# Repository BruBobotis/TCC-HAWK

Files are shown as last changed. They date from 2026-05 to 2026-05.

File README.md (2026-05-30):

<div align="center">

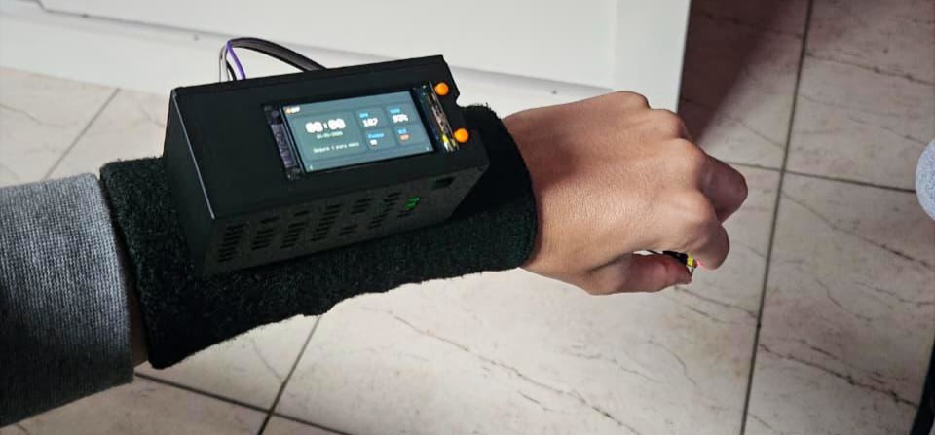
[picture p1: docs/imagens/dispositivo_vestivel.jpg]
Logo HAWK


# TCC-HAWK  
### Health Assistant Watch Kare

Sistema vestível para cuidado geriátrico com monitoramento de sinais vitais, detecção de quedas, comunicação BLE e aplicativo Android nativo.

</div>

<p align="center">
  
  
  
  
  
  
</p>

<p align="center">
  <a href="#visão-geral">Visão Geral</a> •
  <a href="#principais-funcionalidades">Funcionalidades</a> •
  <a href="#arquitetura-geral-do-sistema">Arquitetura</a> •
  <a href="#aplicativo-android">Aplicativo</a> •
  <a href="#como-executar-o-projeto">Como Executar</a>
</p>

## Visão Geral

O HAWK é um sistema de monitoramento geriátrico desenvolvido como Trabalho de Conclusão de Curso em Engenharia de Controle e Automação para Faculdade Engenheiro Salvador Arena. O projeto consiste em um dispositivo vestível, no formato de relógio inteligente, integrado a um aplicativo Android nativo. A solução foi criada com o objetivo de auxiliar no acompanhamento de idosos, permitindo a visualização de dados fisiológicos, monitoramento de movimento, detecção de quedas, emissão de alertas e futura integração com armazenamento em nuvem.

O sistema foi desenvolvido ao longo de aproximadamente um ano, passando por etapas de prototipagem eletrônica, programação embarcada, desenvolvimento mobile, comunicação Bluetooth Low Energy, testes funcionais, documentação técnica e refinamento da interface.

O nome HAWK foi escolhido em referência ao falcão, símbolo de vigilância, atenção e resposta rápida. Essa ideia representa a proposta do sistema: acompanhar continuamente o usuário e gerar alertas em situações críticas.
<p align="center">
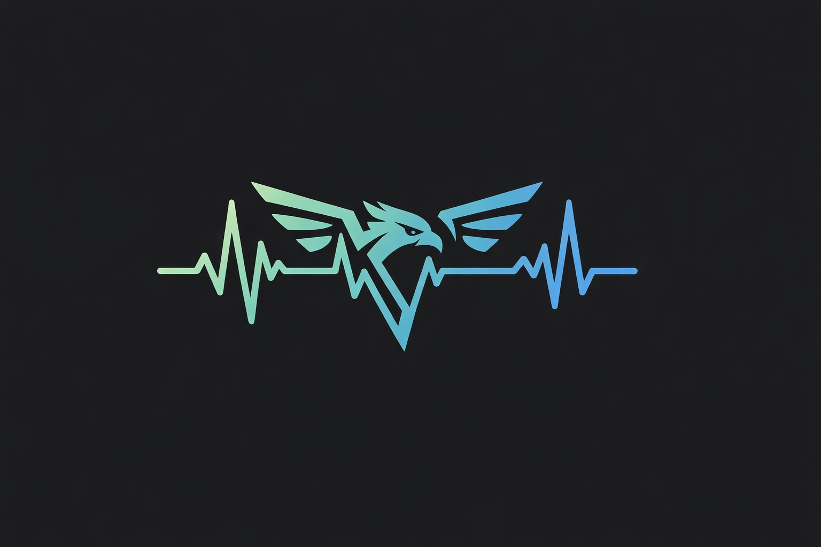
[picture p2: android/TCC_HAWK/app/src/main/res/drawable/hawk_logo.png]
Logo do Projeto HAWK
  
</p>

---

## Equipe de Desenvolvimento

Projeto desenvolvido como Projeto Final de Curso em Engenharia de Controle e Automação pela Faculdade Engenheiro Salvador Arena.

| Integrante | RA |
|---|---|
| Bruno Alves Guirado | 062210033 |
| Guilherme Fernando de Oliveira Bezerra | 062210038 |
| Guilherme do Nascimento de Souza | 062210016 |
| Lucas Guedes Pereira | 062210002 |
| Pedro Henrique Mateus Ribeiro | 062220039 |

<!--<p align="center">
  <img src="docs/imagens/theMans.jpeg" width="500" alt="Os vagabundos que um dia houveram sonhar"/>
</p>

* Com aparição do nosso companheiro Vinicius Koiti, que felizmente não estava em nosso grupo.
-->
---

## Objetivo do Projeto

O objetivo principal do projeto é desenvolver um dispositivo vestível capaz de monitorar parâmetros básicos de saúde e movimento de um usuário idoso, transmitindo essas informações para um aplicativo móvel Android. O sistema busca oferecer uma interface simples, intuitiva e acessível, permitindo que o usuário ou cuidador acompanhe dados como frequência cardíaca, saturação de oxigênio, passos, movimento, repouso e eventos de queda.

Além disso, o projeto foi estruturado para permitir futuras expansões, como armazenamento em nuvem, geração automática de relatórios, acesso por cuidadores e integração com banco de dados remoto.

---

## Principais Funcionalidades

O sistema implementa as seguintes funcionalidades:

| Categoria | Funcionalidades |
|---|---|
| Monitoramento | Frequência cardíaca, SpO₂, passos, movimento e repouso |
| Segurança | Detecção de queda, alerta sonoro, vibração e tela cheia |
| Comunicação | Bluetooth Low Energy entre relógio e aplicativo |
| Aplicativo | Dashboard, alertas, relatórios, cuidadores e configurações |
| Personalização | Cadastro do usuário, limites de BPM e SpO₂, lembretes de água, remédio e sono |
| Expansão | Estrutura preparada para integração com banco de dados em nuvem |

---

## Arquitetura Geral do Sistema

A arquitetura do HAWK é composta por duas camadas principais: o sistema embarcado e a aplicação móvel Android.

O sistema embarcado é responsável pela aquisição dos dados dos sensores, processamento local das informações, exibição no display do relógio, controle por botões físicos e comunicação BLE. Já o aplicativo Android atua como interface principal de visualização e controle, recebendo os dados do relógio, exibindo informações ao usuário, gerando alertas e preparando os dados para integração futura com a nuvem.

Fluxo geral:

```text
Sensores → ESP32-S3 → BLE → Aplicativo Android → Alertas / Relatórios / Nuvem
```

<p align="center">
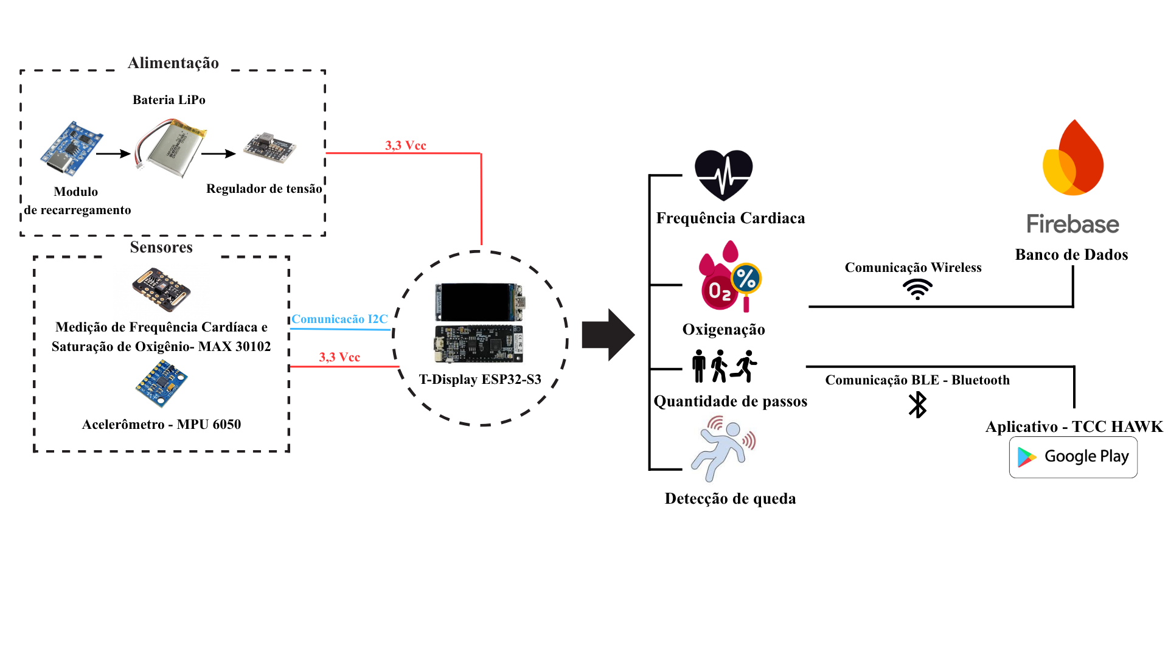
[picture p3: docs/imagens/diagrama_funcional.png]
diagrama funcional
  
</p>

---

## Hardware Utilizado

O protótipo foi desenvolvido utilizando os seguintes componentes principais:

* LilyGo T-Display ESP32-S3;
* Sensor MPU6050;
* Sensor MAX30102;
* Botões físicos para navegação;
* Conexão USB-C para alimentação e programação;
* Jumpers, soldagem e estrutura de montagem;
* Case/protótipo físico para acomodação dos componentes.
<p align="center">
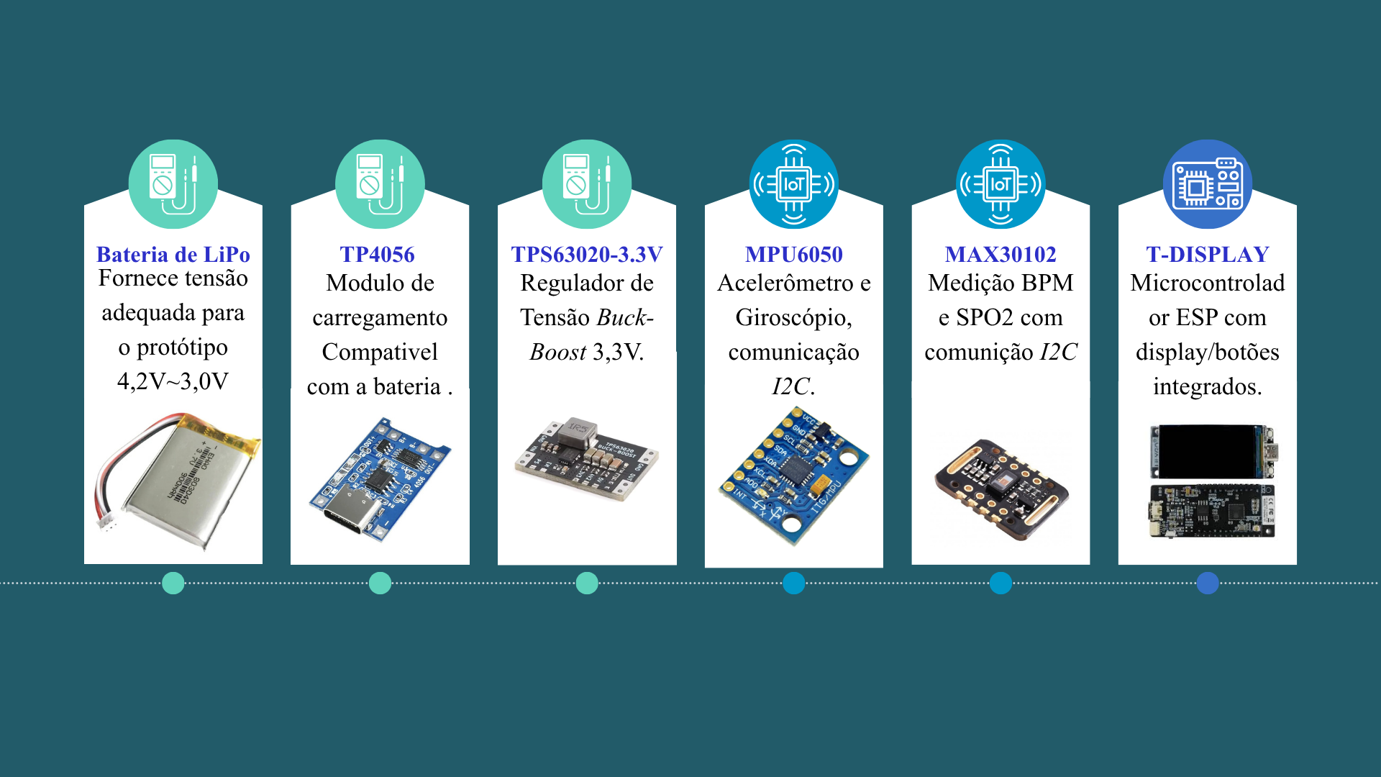
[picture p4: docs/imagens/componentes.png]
componentes
  
</p>

---

## Firmware Embarcado

O firmware foi desenvolvido em C++ utilizando a Arduino IDE. A programação embarcada foi responsável por controlar os sensores, display, botões, lógica de telas, alertas locais e comunicação BLE.

O código embarcado foi estruturado com uma lógica modular, separando as principais responsabilidades do sistema. Entre as funções implementadas estão:

* Inicialização dos periféricos;
* Configuração da comunicação I2C;
* Leitura do MPU6050;
* Leitura do MAX30102;
* Cálculo de passos;
* Análise de movimento;
* Identificação de possível queda;
* Controle das telas do relógio;
* Controle de brilho;
* Recebimento de comandos BLE;
* Envio periódico de dados para o aplicativo.

A interface do relógio foi organizada por uma máquina de estados, permitindo alternância entre telas de horário, dados de saúde, passos, alertas e configurações. Essa abordagem facilitou a navegação por botões físicos e organizou melhor a atualização das informações no display.

---

## Sensores

### MPU6050

O MPU6050 foi utilizado para leitura de aceleração nos três eixos. A partir desses dados, o sistema realiza a análise de movimento, contagem de passos e identificação de possível queda.

A detecção de queda foi baseada na análise da variação de aceleração nos eixos X, Y e Z, identificando movimentos bruscos compatíveis com impacto. Quando o relógio identifica uma possível queda, envia ao aplicativo um sinal específico indicando o evento.

### MAX30102

O MAX30102 foi utilizado para estimativa de frequência cardíaca e saturação de oxigênio. As leituras dependem do contato adequado do sensor com a pele, sendo utilizadas no protótipo como valores indicativos. O módulo não possui validação clínica, sendo empregado com finalidade experimental e demonstrativa no contexto do projeto.

---

## Comunicação BLE

A comunicação entre o relógio e o aplicativo Android ocorre por Bluetooth Low Energy. O relógio atua como dispositivo periférico BLE, enquanto o celular atua como dispositivo central.

O fluxo implementado envolve:

1. Inicialização do relógio;
2. Abertura do aplicativo Android;
3. Busca pelo dispositivo BLE;
4. Conexão entre celular e relógio;
5. Descoberta dos serviços e características;
6. Habilitação de notificações;
7. Sincronização de data e hora;
8. Envio periódico dos dados do relógio para o aplicativo;
9. Envio de comandos do aplicativo para o relógio.

O payload enviado pelo relógio inclui informações como:

```text
BPM
SpO2
Passos
Queda
Aceleração X
Aceleração Y
Aceleração Z
Status do MPU
Status do sensor de dedo
```

O aplicativo interpreta esses dados e atualiza a interface em tempo real.

---

## Aplicativo Android

O aplicativo móvel foi desenvolvido em Kotlin utilizando Android Studio e Jetpack Compose. Ele foi projetado para ser a principal interface de interação do sistema, exibindo os dados recebidos do relógio e permitindo o gerenciamento de alertas, relatórios e configurações.

A arquitetura do aplicativo foi organizada em camadas:

* Interface gráfica em Jetpack Compose;
* ViewModels para controle de estado;
* Repositório para comunicação BLE;
* Modelos de dados;
* Sistema de alertas;
* Estrutura inicial para comunicação com nuvem.

---

## Telas do Aplicativo

O aplicativo possui as seguintes telas principais:

### Dashboard

A tela principal apresenta os principais dados monitorados pelo relógio:

* Frequência cardíaca;
* Saturação de oxigênio;
* Passos;
* Tempo em movimento;
* Tempo em repouso;
* Dados do acelerômetro;
* Status de queda;
* Status de conexão com o relógio;
* Relatório diário de saúde.

Os cards foram refinados para uma interface mais limpa, moderna e premium, com cores suaves, ícones, organização visual e atualização dinâmica dos dados.

### Alertas

A tela de alertas registra eventos importantes, como:

* Queda detectada;
* Batimento alto;
* Batimento baixo;
* Oxigenação baixa;
* Lembretes de hidratação;
* Lembretes de remédio;
* Lembretes de sono;
* Alertas gerais.

Os alertas críticos são exibidos em tela cheia, com som, vibração e notificação visual.

<p align="center">
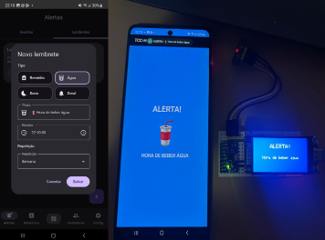
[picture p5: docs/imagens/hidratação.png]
alerta_agua
  
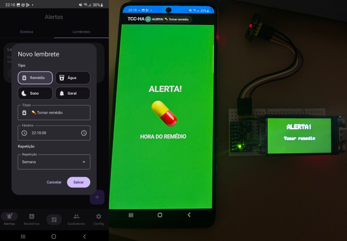
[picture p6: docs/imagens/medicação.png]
alertas_remedio
  
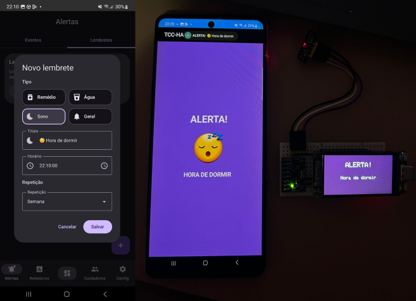
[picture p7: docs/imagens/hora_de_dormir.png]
alertas_dormir
  
</p>

### Relatórios

A tela de relatórios foi planejada para apresentar dados consolidados do usuário, como histórico de batimentos, SpO₂, passos, quedas e eventos críticos. A proposta é permitir acompanhamento diário, semanal e mensal.

### Cuidadores

A tela de cuidadores foi planejada para cadastrar responsáveis pelo usuário monitorado. A ideia é permitir o registro de nome, telefone, e-mail, relação com o paciente e prioridade de contato.

### Configurações

A tela de configurações reúne ajustes gerais do aplicativo e do relógio, como conexão BLE, sincronização de horário, testes de alerta, preferências do sistema e futuras opções de integração com nuvem.

### Cadastro do Usuário

O cadastro inicial coleta informações importantes do paciente, como:

* Nome;
* Data de nascimento;
* Peso;
* Altura;
* Sexo;
* Horários de sono;
* Mobilidade;
* Histórico de quedas;
* Hipertensão;
* Diabetes;
* Problemas cardíacos;
* Problemas respiratórios;
* Uso de medicação contínua;
* Limites personalizados de taquicardia e bradicardia;
* Limites de SpO₂;
* Contato de emergência;
* Observações médicas.

Essas informações permitem personalizar os alertas e melhorar o contexto do monitoramento.

---

## Alerta de Queda

O alerta de queda é uma das principais funcionalidades do projeto. Quando o relógio detecta uma possível queda, envia o status ao aplicativo por BLE. O aplicativo, ao identificar esse evento, executa as seguintes ações:

* Atualiza o card de acelerômetro/queda;
* Registra o evento na tela de alertas;
* Exibe uma tela cheia de alerta crítico;
* Emite som de alarme;
* Ativa vibração;
* Exibe notificação de alta prioridade.

Esse comportamento busca chamar a atenção do usuário ou cuidador em situações de risco.
<p align="center">
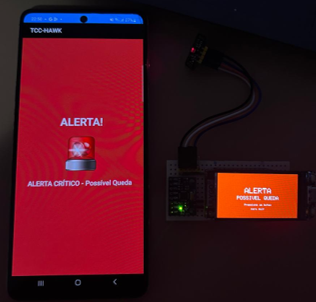
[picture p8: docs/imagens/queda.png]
queda
  
</p>

---

## Integração com Nuvem

Durante o desenvolvimento, foi estudada a integração com banco de dados em nuvem para armazenamento histórico dos dados. Foram avaliadas arquiteturas baseadas em MQTT, InfluxDB e Firebase.

A proposta final considerada para expansão do sistema foi utilizar o aplicativo Android como gateway entre o relógio e a nuvem. Nesse modelo, o relógio envia os dados por BLE ao celular, e o aplicativo organiza essas informações e as envia para uma plataforma em nuvem do Firebase.

Fluxo proposto:

```text
Relógio ESP32 → BLE → Aplicativo Android → Nuvem → Histórico / Relatórios / Cuidadores
```

Para telemetria IoT, o uso de MQTT com banco de séries temporais é uma possibilidade futura. Para integração mais rápida com autenticação, múltiplos dispositivos e sincronização de dados, o Firebase foi considerado uma alternativa adequada.

---

## Testes Realizados

Durante o desenvolvimento foram realizados testes funcionais envolvendo:

* Comunicação BLE entre relógio e celular;
* Sincronização de data e hora;
* Envio de dados do relógio para o aplicativo;
* Atualização dos cards no dashboard;
* Leitura do acelerômetro;
* Detecção de movimento;
* Testes de queda;
* Alertas em tela cheia;
* Vibração e som em eventos críticos;
* Alertas de BPM e SpO₂;
* Funcionamento dos lembretes;
* Testes de interface;
* Validação do payload BLE com nRF Connect.

O nRF Connect foi utilizado como ferramenta auxiliar para verificar serviços BLE, características e dados transmitidos pelo relógio.

---

## Tecnologias Utilizadas

| Camada | Tecnologias | Responsabilidade |
|---|---|---|
| Sistema Embarcado | C++, Arduino IDE, ESP32-S3, KiCad, Inventor | Sensores, display, botões, BLE e lógica local |
| Aplicativo Mobile | Kotlin, Android Studio, Jetpack Compose | Interface, dashboard, alertas, relatórios e cuidadores |
| Backend em Nuvem | Firebase, Cloud Firestore, Cloud Functions | Armazenamento, histórico, relatórios e sincronização futura |
| Comunicação | Bluetooth Low Energy | Troca de dados entre relógio e aplicativo |

<p align="center">
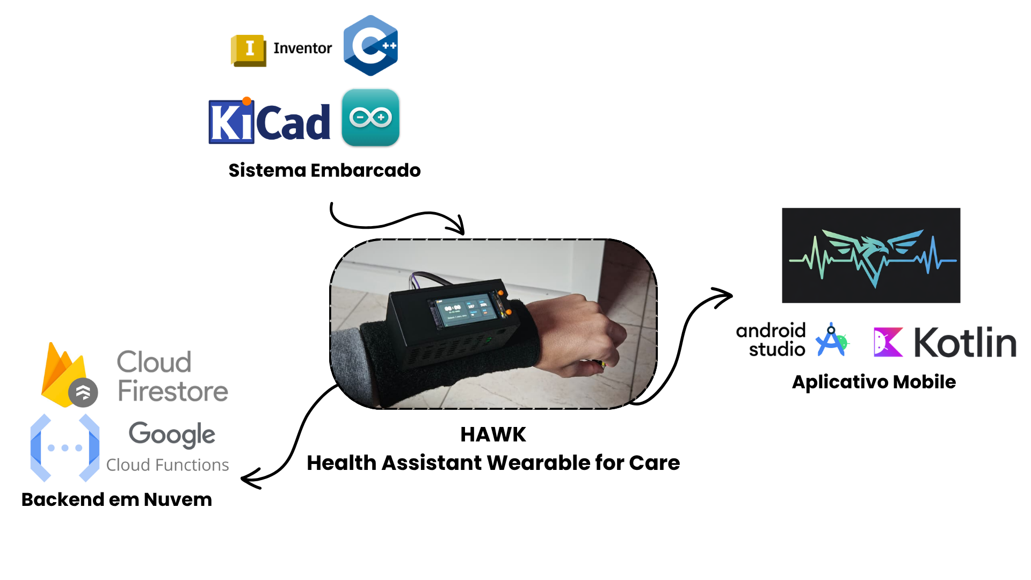
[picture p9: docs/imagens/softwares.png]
Tecnologias utilizadas no projeto HAWK
  
</p>

---

## Protocolo de Dados

O relógio envia os dados em formato textual estruturado, utilizando pares chave-valor. O aplicativo interpreta esse payload e converte os dados para estruturas internas.

Exemplo conceitual de payload:

```text
BPM:80;SPO2:97;P:1200;Q:0;X:0.12;Y:-0.04;Z:0.98;MPU:1;F:1;
```

Campos principais:

* `BPM`: frequência cardíaca;
* `SPO2`: saturação de oxigênio;
* `P`: passos;
* `Q`: status de queda;
* `X`, `Y`, `Z`: aceleração;
* `MPU`: status do acelerômetro;
* `F`: detecção do dedo no sensor óptico.

---

## Dimensão do Desenvolvimento

| Módulo | Tecnologia | Responsabilidade |
|---|---|---|
| Firmware Embarcado | C++ / Arduino IDE | Sensores, display, botões, BLE e alertas locais |
| Aplicativo Mobile | Kotlin / Jetpack Compose | Interface, BLE, alertas, relatórios e cuidadores |
| Comunicação | Bluetooth Low Energy | Troca de dados entre relógio e celular |
| Sensoriamento | MPU6050 e MAX30102 | Movimento, queda, BPM e SpO₂ |
| Expansão em Nuvem | Firebase / MQTT | Histórico, relatórios e acesso remoto |

---

## Resultados Obtidos

O projeto resultou em um protótipo funcional composto por relógio vestível e aplicativo Android. O sistema foi capaz de realizar comunicação BLE, transmitir dados dos sensores, atualizar a interface do aplicativo, gerar alertas e registrar eventos críticos.

Entre os principais resultados obtidos estão:

* Funcionamento da comunicação BLE bidirecional;
* Sincronização de horário do celular para o relógio;
* Exibição dos dados no dashboard;
* Alertas visuais e sonoros no celular;
* Detecção e registro de queda;
* Interface mobile refinada;
* Estrutura modular do firmware;
* Separação das camadas do aplicativo;
* Preparação para integração com banco de dados em nuvem.

---

## Limitações

O projeto apresenta algumas limitações:

* O MAX30102 não possui validação clínica no protótipo;
* A detecção de queda utiliza limiares e lógica simplificada;
* A contagem de passos é experimental;
* A comunicação BLE depende da proximidade entre celular e relógio;
* A integração em nuvem foi estruturada como proposta de expansão;
* O protótipo ainda não possui case final industrializado;
* O consumo de bateria ainda pode ser otimizado.

---

## Possibilidades Futuras

Como melhorias futuras, destacam-se:

* Integração completa com Firebase ou banco em nuvem;
* Login com conta Google;
* Acesso remoto por cuidadores;
* Geração automática de relatórios mensais;
* Envio automático de relatórios por e-mail;
* Aplicação de filtros digitais nos dados do acelerômetro;
* Melhoria do algoritmo de detecção de queda;
* Calibração individual dos sensores;
* Otimização de bateria;
* Desenvolvimento de case final impresso em 3D;
* Integração com serviços de emergência;
* Armazenamento histórico em banco de dados;
* Notificações remotas para familiares.

---

## Estrutura do Repositório

```text
TCC-HAWK/
│
├── firmware/
│   └── esp32_hawk_watch/
│       ├── esp32_hawk_watch.ino
│       ├── alerts.cpp
│       ├── alerts.h
│
├── android/
│   └── TCC_HAWK/
│        ├── build.gradle.kts
│        ├── settings.gradle.kts
│        ├── gradle.properties
│        ├── gradlew
│        ├── gradlew.bat
│        ├── gradle/
│        │   ├── libs.versions.toml
│        │   └── wrapper/
│        │       ├── gradle-wrapper.jar
│        │       └── gradle-wrapper.properties
│        │
│        └── app/
│            ├── build.gradle.kts
│            ├── proguard-rules.pro
│            │
│            └── src/
│                ├── main/
│                │   ├── AndroidManifest.xml
│                │   │
│                │   ├── java/com/example/tcc_hawk/
│                │   │   ├── MainActivity.kt
│                │   │   │
│                │   │   ├── data/
│                │   │   │   ├── alarms/
│                │   │   │   │   ├── AlarmReceiver.kt
│                │   │   │   │   └── AlarmScheduler.kt
│                │   │   │   │
│                │   │   │   ├── ble/
│                │   │   │   │   └── HawkBleUuids.kt
│                │   │   │   │
│                │   │   │   ├── local/
│                │   │   │   │   ├── PreferencesStore.kt
│                │   │   │   │   └── ThemePrefs.kt
│                │   │   │   │
│                │   │   │   ├── model/
│                │   │   │   │   ├── Models.kt
│                │   │   │   │   └── PatientProfile.kt
│                │   │   │   │
│                │   │   │   ├── mqtt/
│                │   │   │   │   └── MqttManager.kt
│                │   │   │   │
│                │   │   │   └── repository/
│                │   │   │       ├── HawkRepository.kt
│                │   │   │       ├── RepositoryProvider.kt
│                │   │   │       ├── ble/
│                │   │   │       │   └── BleHawkRepository.kt
│                │   │   │       └── fake/
│                │   │   │           └── FakeHawkRepository.kt
│                │   │   │
│                │   │   └── ui/
│                │   │       ├── components/
│                │   │       │   ├── DatePickerField.kt
│                │   │       │   └── TimePickerField.kt
│                │   │       │
│                │   │       ├── navigation/
│                │   │       │   └── AppNav.kt
│                │   │       │
│                │   │       ├── screens/
│                │   │       │   ├── alerts/
│                │   │       │   │   ├── AlertFullScreenActivity.kt
│                │   │       │   │   ├── AlertsFullScreen.kt
│                │   │       │   │   └── AlertsScreen.kt
│                │   │       │   │
│                │   │       │   ├── auth/
│                │   │       │   │   └── AuthScreen.kt
│                │   │       │   │
│                │   │       │   ├── caregivers/
│                │   │       │   │   └── CaregiversScreen.kt
│                │   │       │   │
│                │   │       │   ├── dashboard/
│                │   │       │   │   └── DashboardScreen.kt
│                │   │       │   │
│                │   │       │   ├── main/
│                │   │       │   │   └── MainScreen.kt
│                │   │       │   │
│                │   │       │   ├── onboarding/
│                │   │       │   │   └── OnboardingScreen.kt
│                │   │       │   │
│                │   │       │   ├── reports/
│                │   │       │   │   └── ReportsScreen.kt
│                │   │       │   │
│                │   │       │   ├── settings/
│                │   │       │   │   ├── SettingsScreen.kt
│                │   │       │   │   └── SettingsViewModel.kt
│                │   │       │   │
│                │   │       │   └── splash/
│                │   │       │       └── SplashScreen.kt
│                │   │       │
│                │   │       ├── state/
│                │   │       │   └── DashboardUiState.kt
│                │   │       │
│                │   │       ├── theme/
│                │   │       │   ├── AppThemeState.kt
│                │   │       │   ├── Color.kt
│                │   │       │   ├── Theme.kt
│                │   │       │   └── Type.kt
│                │   │       │
│                │   │       └── viewmodel/
│                │   │           ├── AlertsViewModel.kt
│                │   │           └── DashboardViewModel.kt
│                │   │
│                │   └── res/
│                │       ├── drawable/
│                │       │   ├── hawk_logo.png
│                │       │   ├── hawk_logo_background.xml
│                │       │   ├── ic_launcher_background.xml
│                │       │   └── ic_launcher_foreground.xml
│                │       │
│                │       ├── mipmap-*/
│                │       │   ├── hawk_logo.webp
│                │       │   ├── hawk_logo_foreground.webp
│                │       │   ├── hawk_logo_round.webp
│                │       │   ├── ic_launcher.webp
│                │       │   ├── ic_launcher_foreground.webp
│                │       │   └── ic_launcher_round.webp
│                │       │
│                │       ├── values/
│                │       │   ├── colors.xml
│                │       │   ├── ic_launcher_background.xml
│                │       │   ├── strings.xml
│                │       │   └── themes.xml
│                │       │
│                │       └── xml/
│                │           ├── backup_rules.xml
│                │           └── data_extraction_rules.xml
│                │
│                ├── androidTest/
│                │   └── java/com/example/tcc_hawk/
│                │       └── ExampleInstrumentedTest.kt
│                │
│                └── test/
│                    └── java/com/example/tcc_hawk/
│                        └── ExampleUnitTest.kt
│
├── docs/
│   ├── fluxogramas/
│       ├── logica_funcionamento.png
│       ├── detecção_queda.png
│   ├── imagens/
│       ├── diagrama_funcional.png
│       ├── softwares.png
│       ├── testes.png
│       ├── componentes.png
│       ├── protótipo_final.jpg
│       ├── protótipo_inicial.jpg
│       ├── montagem_protótipo.jpg
│       ├── dispositivo_vestivel.jpg
│       ├── theMans.jpeg
│       ├── hora_de_dormir.png
│       ├── medicação.png
│       ├── hidratação.png
│       ├── queda.png
│   └── artigo/
│       ├── PFC_Desenvolvimento de um dispositivo vestível para cuidado geriátrico com integração IoT - V2.2
│
├── esquematicos/
│   └── eletronico/
│       ├── eletronico.kicad_sch/
│   └── mecanico/
│       └── OldVersions/
│           ├── carcaça final.0017.ipt
│           ├── montagem_final_v2.0001.iam
│           ├── tampa final.0012.ipt
│       ├── botão final.ipt
│       ├── botão final.stl
│       ├── carcaça final.ipt
│       ├── carcaça final.stl
│       ├── Montagem_final.iam
│       ├── montagem_final_v2.iam
│       ├── tampa final.ipt
│       ├── tampa final.stl
│ 
└── README.md
```

---

## Como Executar o Projeto

### Firmware

1. Abrir o código do firmware na Arduino IDE;
2. Selecionar a placa ESP32-S3 correspondente;
3. Instalar as bibliotecas necessárias;
4. Conectar o dispositivo via USB-C;
5. Compilar e enviar o código para o relógio.

### Aplicativo Android

1. Abrir o projeto no Android Studio;
2. Sincronizar as dependências Gradle;
3. Conectar um smartphone Android;
4. Conceder permissões de Bluetooth, localização e notificações;
5. Executar o aplicativo;
6. Ligar o relógio;
7. Realizar a conexão BLE pelo app.

---
## Observação

O sistema desenvolvido possui finalidade acadêmica e experimental. Os dados fisiológicos apresentados são indicativos e não substituem equipamentos médicos certificados ou avaliação profissional. O projeto tem como objetivo demonstrar a integração entre sistemas embarcados, sensores, comunicação IoT e aplicação móvel no contexto de cuidado geriátrico.

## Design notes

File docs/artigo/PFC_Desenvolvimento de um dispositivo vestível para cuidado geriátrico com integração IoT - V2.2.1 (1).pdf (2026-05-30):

1
Curso Superior de Bacharelado em Engenharia de Controle e Automação - São Bernardo do Campo - SP -Brasil - 8 a 11 de junho de 2026

V-05

Desenvolvimento de um dispositivo vestível para cuidado geriátrico com integração IoT

Autores: Bruno Alves Guirado, Guilherme Fernando de Oliveira Bezerra, Guilherme Nascimento de Souza, Lucas Guedes Pereira, Pedro Henrique Mateus Ribeiro¹

Orientador: Prof. Me. Glauco Rigolin

Resumo

O envelhecimento populacional tem ampliado a necessidade de soluções tecnológicas capazes de contribuir para a segurança, autonomia e qualidade de vida da população idosa. Nesse contexto, dispositivos vestíveis e sistemas baseados em Internet das Coisas têm se destacado como alternativas para o monitoramento contínuo de sinais fisiológicos e eventos de risco, como quedas, conforme apontado por Ferreira et al. (2024), Diniz et al. (2022) e Silva et al. (2023). Este artigo tem como objetivo apresentar o desenvolvimento de um dispositivo vestível para cuidado geriátrico com integração IoT, destinado ao monitoramento de parâmetros fisiológicos e de movimentação do usuário. A metodologia envolveu a concepção mecânica do protótipo, a elaboração do circuito eletrônico, a integração dos sensores MAX30102 e MPU6050, o desenvolvimento do firmware em C++ para o ESP32-S3 e a criação de uma aplicação Android para visualização dos dados por meio de comunicação Bluetooth Low Energy. Os resultados indicaram o funcionamento integrado do sistema, permitindo a leitura de frequência cardíaca, oxigenação sanguínea, contagem de passos, análise de movimento e identificação de possíveis quedas. Conclui-se que o protótipo desenvolvido possui potencial como ferramenta experimental de apoio ao cuidado geriátrico, embora ainda demande aprimoramentos, calibração individual e validações adicionais.

Palavras-chave: Dispositivo vestível. Cuidado geriátrico. Internet das Coisas. Monitoramento remoto. ESP32.

Abstract

Population aging has increased the need for technological solutions capable of contributing to the safety, independence, and quality of life of the elderly population. In this context, wearable devices and systems based on the Internet of Things have emerged as alternatives for the continuous monitoring of physiological signals and risk events, such as falls, as noted by Ferreira et al. (2024), Diniz et al. (2022), and Silva et al. (2023). This article aims to present the development of a wearable device for geriatric care with IoT integration, designed to monitor the user’s physiological and movement parameters. The methodology involved the mechanical design of the prototype, the development of the electronic circuit, the integration of the MAX30102 and MPU6050 sensors, the development of firmware in C++ for the ESP32-S3, and the creation of an Android application for data visualization via Bluetooth Low Energy communication. The results indicated the integrated operation of the system, enabling the reading of heart rate, blood oxygenation, step counting, movement analysis, and the identification of potential falls. It is concluded that the developed prototype has potential as an experimental tool to support geriatric care, although it still requires improvements, individual calibration and additional validations.

Keywords: Wearable device. Geriatric care. Internet of Things. Remote monitoring. ESP32.

2

### 1 Introdução

O envelhecimento populacional tem se intensificado nas últimas décadas, configurando-se como um dos principais desafios sociais e de saúde pública do século XXI. De acordo com a Organização Mundial da Saúde (OMS, 2023), entre 2015 e 2050, a proporção da população mundial com mais de 60 anos quase dobrará, de 12% para 22%, o que demanda soluções inovadoras para garantir qualidade de vida, segurança e autonomia a essa parcela da população. No Brasil, esse cenário é igualmente expressivo, de acordo com o IBGE (2023), o índice de envelhecimento chegou a 55,2 em 2022, indicando que há 55,2 pessoas com 65 anos ou mais de idade para cada 100 crianças de 0 a 14 anos. Em 2010, o índice era de 30,7.
Nesse contexto, diversas pesquisas têm apontado o potencial de dispositivos vestíveis e da Internet das Coisas (IoT) no monitoramento contínuo da saúde, especialmente no auxílio à prevenção de quedas e na detecção precoce de situações críticas (ALMEIDA et al., 2024; DINIZ et al., 2022).
Este projeto tem como objetivo desenvolver um dispositivo vestível para cuidado geriátrico, implementado no formato de bracelete, que seja capaz de monitorar parâmetros fisiológicos do usuário, processar informações por meio de algoritmos e monitorar a movimentação do usuário. Como parte do desenvolvimento, foram realizados o projeto e a montagem da estrutura mecânica, a elaboração do diagrama elétrico, a montagem dos componentes, o desenvolvimento da programação para coleta e análise dos dados dos sensores e detecção de situações críticas, o desenvolvimento do aplicativo e os testes da solução para validação do cuidado geriátrico.

### 2 Referencial teórico

Neste tópico serão apresentados os projetos e estudos relacionados ao desenvolvimento de soluções voltadas para o cuidado geriátrico com integração de Internet das Coisas (IoT). Esses trabalhos abordam tecnologias aplicadas à promoção de segurança, conforto e autonomia para pessoas idosas, destacando arquiteturas, metodologias e resultados obtidos em protótipos e implementações práticas. Cada descrição contempla os objetivos, recursos tecnológicos empregados e as principais contribuições das pesquisas analisadas.

### 2.1 Relação entre medidas de Smartwatches e a identificação da síndrome da fragilidade

O estudo de Andrade Ferreira e Gomes da Silva (2024) realizou uma revisão de escopo com o objetivo de descrever e mapear as medidas fornecidas por smartwatches como uma ferramenta potencial para a identificação da Síndrome da Fragilidade em idosos. A Fragilidade é uma condição clínica importante que afeta a saúde dessa população, e o monitoramento contínuo pode auxiliar em sua detecção precoce.
Para o levantamento, os autores incluíram estudos publicados em qualquer idioma, mas focaram naqueles que descreviam o uso de medidas de smartwatches na avaliação da Fragilidade ou de seus critérios. A pesquisa nas bases de dados, como SciELO, identificou artigos que utilizavam, principalmente, as métricas diárias de contagem de passos, dados de sono e Frequência Cardíaca (FC) fornecidas pelos dispositivos vestíveis.
Andrade Ferreira e Gomes da Silva (2024) concluíram que os smartwatches se mostram como uma ferramenta promissora para o monitoramento da fragilidade, especialmente por meio de medições diárias não invasivas de locomoção e padrões fisiológicos. Os resultados obtidos com o uso desses dispositivos sugerem a possibilidade de uma avaliação mais ampla e contínua dos idosos que apresentam risco aumentado para desenvolver a Síndrome da Fragilidade, facilitando intervenções clínicas mais oportunas.

3

### 2.2 Protótipo de aparelho para detecção de quedas em idosos

O trabalho de Marques, Campos e Nascimento (2022) se concentrou na criação e validação de um protótipo de aparelho para detecção de quedas em idosos. A queda é um evento crítico que compromete severamente a qualidade de vida e aumenta a morbidade nessa faixa etária, tornando crucial o desenvolvimento de sistemas de alerta rápido.
Os autores desenvolveram um dispositivo vestível capaz de identificar a ocorrência de quedas por meio de sensores de movimento, com o objetivo de acionar um sistema de alerta imediato. Eles realizaram testes de calibração e confiabilidade do sistema para garantir que o alarme fosse disparado apenas em situações reais de queda, evitando falsos positivos.
Marques, Campos e Nascimento (2022) concluíram que o sistema de alerta implementado atingiu um nível satisfatório de calibração e confiabilidade, funcionando adequadamente em todas as situações analisadas e disparando o alarme apenas nos momentos de queda. Dessa forma, o estudo corrobora a relevância do emprego dessa tecnologia como auxílio no cuidado e na minimização das consequências de acidentes com idosos. A figura 1 ilustra o esquema completo do sistema, apresentando a arquitetura dos componentes, como microcontroladores, emissores, receptores, botão de emergência e alarmes que compõem o protótipo.

Figura 1 – Esquema do sistema implementado e seus componentes

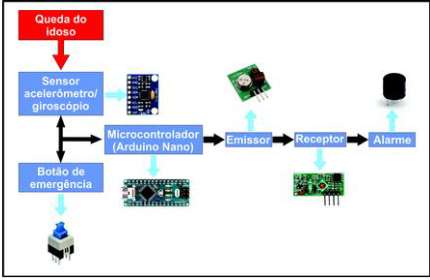
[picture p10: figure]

Fonte: Marques, Campos e Nascimento (2022)

4

### 2.3 SmartCare: as novas tecnologias aplicadas no cuidado de idosos e PCD's

O trabalho de Paulista, Nazaré e Freitas (2022) explora a aplicação de novas tecnologias, como smartwatches e smart homes, no cuidado remoto de idosos e Pessoas com Deficiência (PCDs). O foco principal é a integração entre diferentes dispositivos para criar um sistema de monitoramento realmente inteligente.
O estudo descreve sistemas que não apenas monitoram sinais vitais através do relógio, mas também registram parâmetros de comportamento do usuário. A diferença principal do modelo proposto, denominado SmartCare, é a interligação do relógio inteligente com uma central de casa inteligente. As informações coletadas são enviadas para um banco de dados, permitindo que o algoritmo da casa se torne "inteligente" e passe a auxiliar ativamente no cuidado do monitorado. O sistema foi projetado para ser adaptável a diferentes modelos de relógios e tipos de residências.
Os autores utilizaram uma metodologia de pesquisa exploratória e procederam ao levantamento de artigos científicos para embasamento. A pesquisa concluiu que o sistema proposto visa aprimorar o cuidado remoto, integrando o monitoramento de sinais vitais com dados de comportamento, o que pode aumentar a segurança e a autonomia dos idosos. A viabilidade do sistema reside na sua capacidade de adaptação e na interligação de dispositivos vestíveis a plataformas mais amplas de Internet das Coisas (IoT). A figura 2 ilustra o fluxograma do SmartCare, detalhando como os diferentes módulos do sistema se comunicam.

Figura 2 – Fluxograma SmartCare

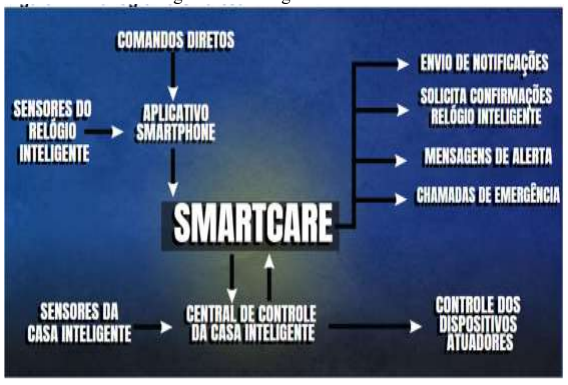
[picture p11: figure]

Fonte: Paulista, Nazaré e Freitas (2022)

5

### 2.4 Gerontecnologias e internet das coisas para prevenção de quedas em idosos

Silva et al. (2023) realizam uma revisão integrativa sobre tecnologias para prevenção de quedas em idosos, identificando as principais soluções baseadas em IoT e sensores inteligentes. Entre os recursos analisados, destacam-se:
- Sensores de movimento e acelerômetros, que detectam quedas e enviam alertas automáticos.
- Pulseiras inteligentes, para monitoramento de localização, frequência cardíaca e nível de atividade.
- Tapetes e pisos inteligentes, que analisam padrões de deslocamento.
O estudo ressalta a importância da integração dessas tecnologias com sistemas de monitoramento remoto, possibilitando que familiares e cuidadores recebam alertas imediatos em casos de emergência. A pesquisa conclui que, embora eficazes, as soluções devem priorizar interfaces intuitivas, baixo consumo de energia e compatibilidade com múltiplos dispositivos IoT, para garantir adesão do público idoso (Silva et al., 2023). A figura 3 apresenta o fluxograma do processo de seleção de artigos utilizado por Silva et al. (2023), ilustrando as etapas metodológicas empregadas em sua revisão integrativa.

Figura 3 – Fluxograma do processo de seleção dos artigos

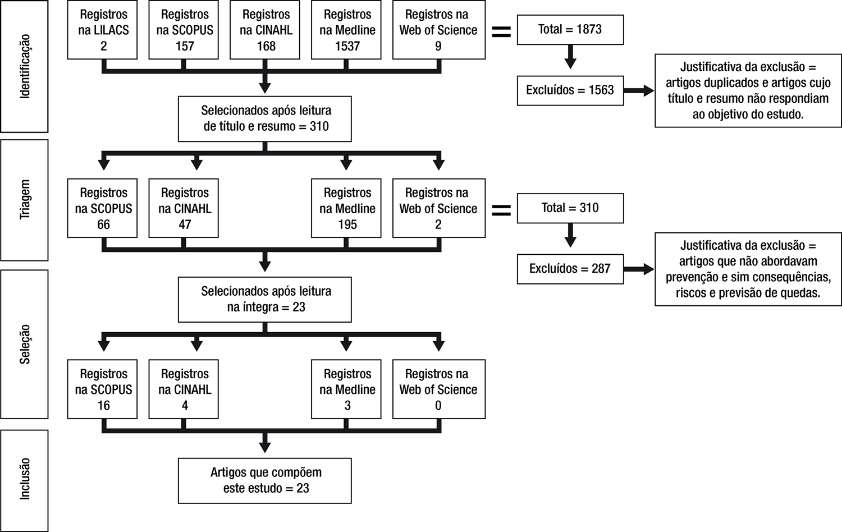
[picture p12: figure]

Fonte: Silva et al. (2023)

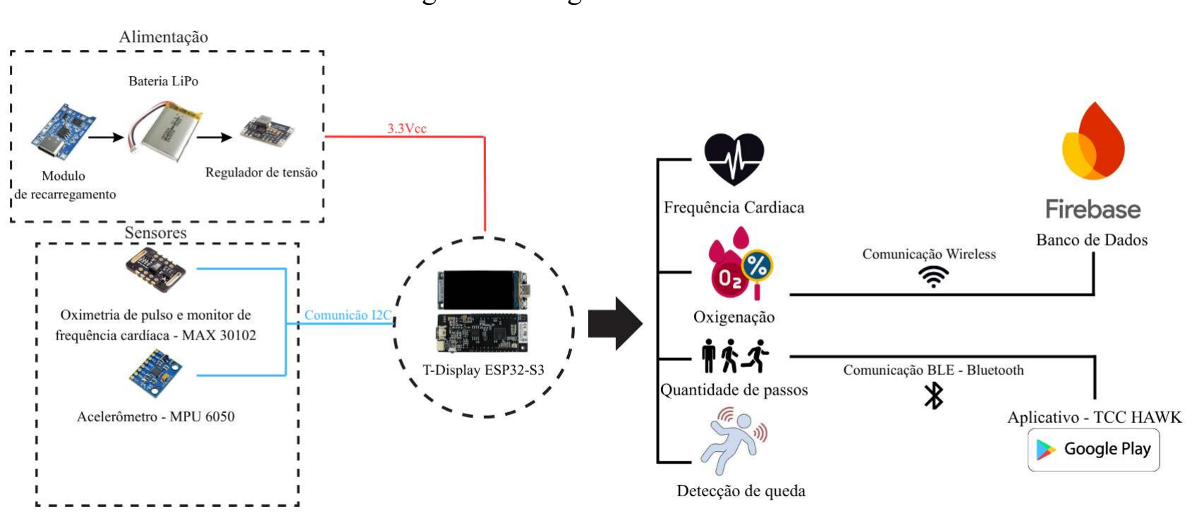
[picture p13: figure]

6

### 3 Metodologia

Neste tópico será apresentado os procedimentos adotados para o desenvolvimento do dispositivo vestível para cuidado geriátrico. Para sua construção foram realizadas as seguintes etapas: desenvolvimento do projeto mecânico do dispositivo e do alojamento dos componentes, elaboração do projeto eletrônico e integração dos sensores, desenvolvimento da programação embarcada, implementação dos algoritmos de monitoramento e análise dos dados e criação da interface de usuário para visualização das informações coletadas.
A metodologia também contempla o levantamento básico dos custos envolvidos na montagem do protótipo e a execução dos testes e validações, que tiveram como objetivo verificar o correto funcionamento dos sensores, da comunicação e do processamento dos dados. Essas etapas possibilitaram avaliar a eficácia do sistema em condições próximas ao uso real.

### 3.1 Composição do protótipo

O protótipo do dispositivo para cuidado geriátrico foi desenvolvido na forma de um dispositivo vestível, composto por um microcontrolador integrado aos sensores responsáveis pela coleta dos dados. A estrutura do sistema foi organizada de modo a garantir baixo consumo de energia, precisão nas medições e comunicação eficiente com a plataforma de monitoramento.
O núcleo do projeto é o microcontrolador T-Display ESP32-S3, responsável pelo processamento dos sinais dos sensores, gerenciamento da comunicação sem fio e envio dos dados ao aplicativo e ao banco de dados. O protótipo utiliza uma bateria Li-Po junto de um módulo de carregamento, associada a um regulador de tensão, garantindo alimentação estável para todos os componentes.
A etapa de sensoriamento é composta por dois dispositivos principais:
- o sensor MAX30102, utilizado para medição de frequência cardíaca e oxigenação sanguínea;
- o sensor inercial MPU6050, responsável por detectar movimento e estimar a quantidade de passos e detecção de queda;
Os dados coletados são tratados pelo microcontrolador e enviados ao aplicativo por meio de comunicação bluetooth (BLE – Bluetooth Low Energy), permitindo acesso em tempo real às informações de saúde do usuário. A figura 4 apresenta o diagrama funcional do sistema, ilustrando a integração entre os módulos de alimentação, sensoriamento, processamento e transmissão dos dados do protótipo.

Figura 4 – Diagrama funcional

Fonte: Autoria própria (2026)

7

### 3.1.1 Projeto e montagem mecânica

O projeto e a montagem mecânica do protótipo foram desenvolvidos com o objetivo de criar uma estrutura compacta, de baixo custo, ergonômica e adequada ao uso contínuo por pessoas idosas. Para isso, foram projetadas 2 peças destinadas a acomodar todos os componentes eletrônicos internos, garantindo proteção, conforto e facilidade na montagem do hardware.
A peça principal foi modelada considerando dimensões reduzidas e cantos arredondados, de forma a evitar desconfortos no pulso. A figura 5 ilustra a peça principal do protótipo com os componentes internos, idealizado com aberturas para realizar a troca de calor dos componentes, com bases para acomodar as 2 placas de circuitos e a bateria, com entradas USB-C, botões e display para o protótipo. A estrutura conta ainda com 2 furos M2 nas bordas, permitindo a união segura com a peça secundária e facilitando futuras manutenções ou substituições de componentes.
A figura 6 ilustra a peça secundária do protótipo, idealizada com 2 furos para a passagem do parafuso M2, um oblongo para a conexão dos cabos com o sensor de FC externo e com aberturas para realizar a troca de calor dos componentes.
O modelo final foi preparado visando fabricação por impressão 3D, uma vez que essa técnica permite ajustes rápidos, baixo custo de produção e maior liberdade geométrica, aspectos essenciais durante as etapas de prototipagem. A montagem mecânica foi realizada inserindo-se a placa controladora, sensores e fiação na peça principal, com passagem adequada para conectores e garantindo a funcionalidade durante o uso cotidiano.
Figura 5 – Vista peça principal | Figura 6 – Vista peça secundária

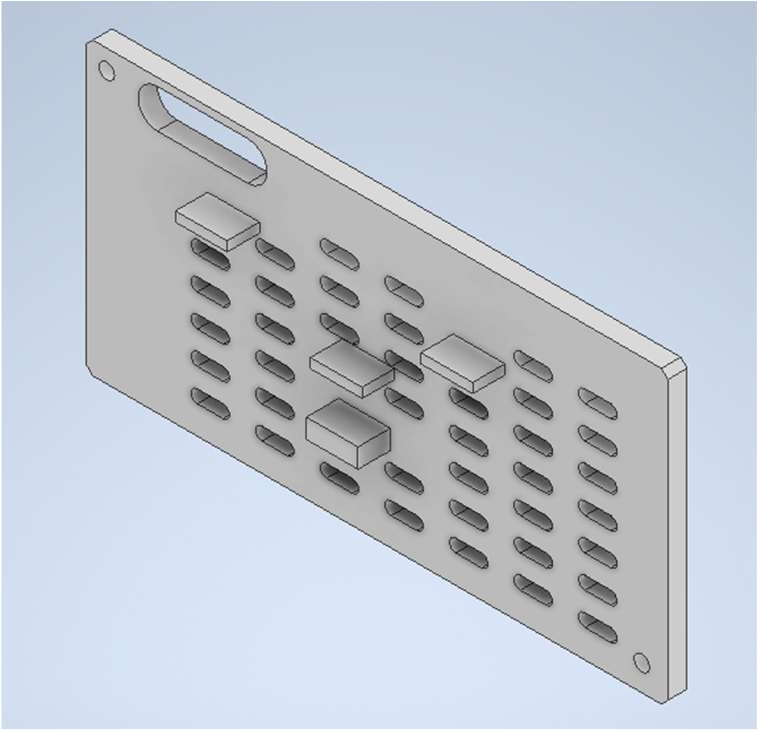
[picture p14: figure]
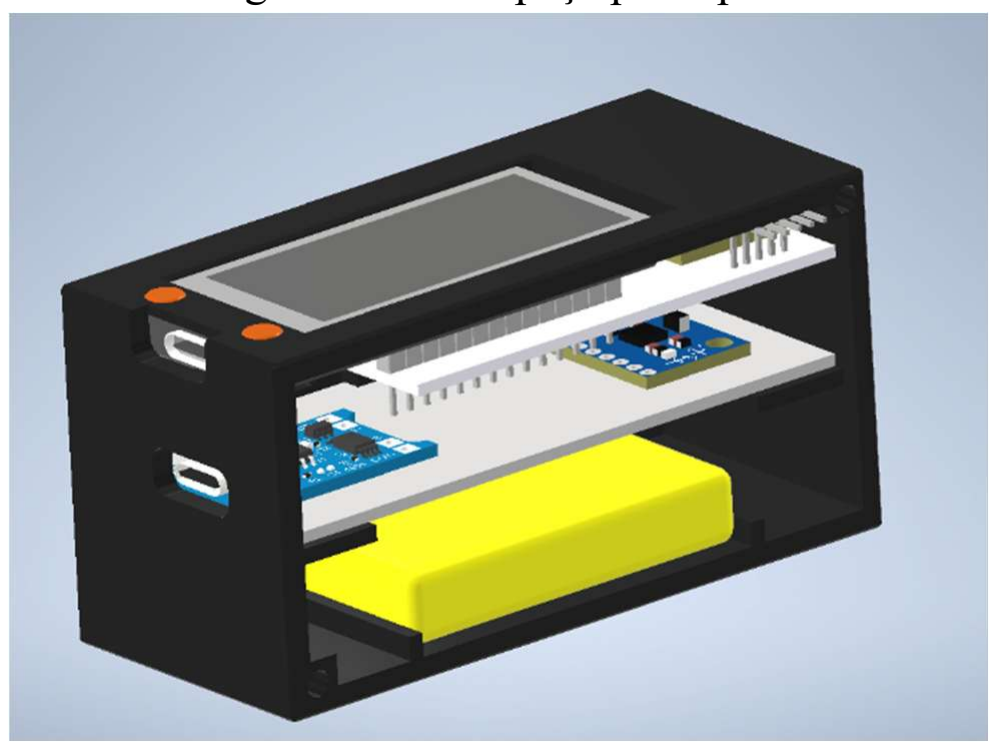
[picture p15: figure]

Fonte: Autoria própria (2026) | Fonte: Autoria própria (2026)

8

### 3.1.2 Diagrama elétrico ou circuito eletrônico

O diagrama elétrico do protótipo foi elaborado com o objetivo de integrar, de forma eficiente e confiável, todos os sensores e módulos responsáveis pela coleta, processamento e transmissão dos dados fisiológicos monitorados pelo relógio. O diagrama esquemático apresentado na figura 7 ilustra a interligação entre os componentes, destacando o fluxo de alimentação, os barramentos de comunicação e as conexões dos sensores.
A alimentação do sistema é realizada por uma bateria de polímero de lítio (Li-Po) de 1800 mAh, que passa pelo módulo carregador TP4056, responsável pela proteção e gerenciamento do carregamento. Em seguida, a tensão é estabilizada por um regulador Buck-Boost TPS 63020-3.3V, que fornece a tensão adequada para o funcionamento da placa T-Display ESP32-S3 e dos demais sensores.
A placa principal utilizada é a ESP32, atuando como unidade de processamento e responsável pela comunicação sem fio com o aplicativo móvel. Os sensores são conectados ao microcontrolador principalmente por comunicação I2C (Inter-Integrated Circuit), um protocolo serial que utiliza dois fios principais: SDA (Serial Data), responsável pela transmissão dos dados, e SCL (Serial Clock), responsável pelo sinal de clock que sincroniza a comunicação. Esse tipo de comunicação permite conectar mais de um dispositivo no mesmo barramento, desde que cada sensor possua um endereço próprio, reduzindo a quantidade de ligações físicas necessárias. Para o correto funcionamento do barramento I2C, é necessária a utilização de resistores de pull-up, normalmente de 4,7 kΩ, ligados entre as linhas SDA/SCL e a alimentação, garantindo níveis lógicos estáveis durante a comunicação. O sensor de frequência cardíaca e oxímetro MAX30102 e o acelerômetro MPU6050 utilizam o barramento I2C, permitindo leitura contínua e simultânea dos sinais.
Também foi integrado ao sistema o display embarcado no módulo LilyGO T-Display S3, responsável pela visualização local dos dados. O display utiliza o controlador ST7789, amplamente empregado em aplicações embarcadas devido ao seu bom desempenho e qualidade de imagem. Embora o controlador ST7789 suporte comunicação via interface SPI, no módulo utilizado a interface é implementada de forma paralela, permitindo maior taxa de transferência de dados.
Todos os componentes compartilham o mesmo plano de terra (GND), conforme recomendado para evitar ruídos e instabilidades.
O circuito foi projetado visando uma maior autonomia da bateria e alta estabilidade, permitindo que o dispositivo funcione de forma contínua e segura no uso cotidiano. A montagem final foi realizada com base no diagrama da figura 7, garantindo que a disposição dos cabos e conexões estivesse compatível com o espaço interno do projeto mecânico.

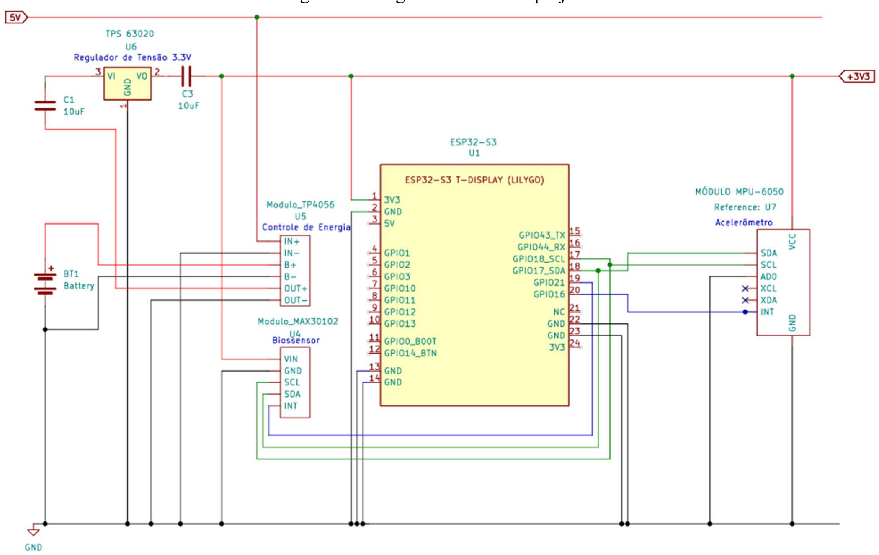
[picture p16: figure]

9

Figura 7 – Diagrama elétrico do projeto

Fonte: Autoria própria (2025)

### 3.1.3 Programação do projeto

A figura 8 apresenta o fluxograma funcional da programação do sistema, demonstrando a interação entre o firmware embarcado no relógio e a aplicação móvel Android. A lógica foi organizada para realizar a leitura contínua dos sensores, o processamento local dos dados, a comunicação Bluetooth Low Energy e a geração de alertas em situações críticas.
A aplicação móvel Android foi desenvolvida em Kotlin, utilizando o Android Studio e a biblioteca Jetpack Compose para construção da interface gráfica. O aplicativo foi estruturado com separação entre camada de interface, controle de estado e comunicação BLE, garantindo melhor organização e manutenção do código. A tela principal apresenta os dados recebidos do relógio em cards visuais, incluindo frequência cardíaca, saturação de oxigênio, passos, tempo em movimento, tempo em repouso e informações do acelerômetro. Também foram implementadas telas para alertas, relatórios, cuidadores, configurações e cadastro do perfil do usuário.

10

Figura 8 – Fluxograma da lógica de programação

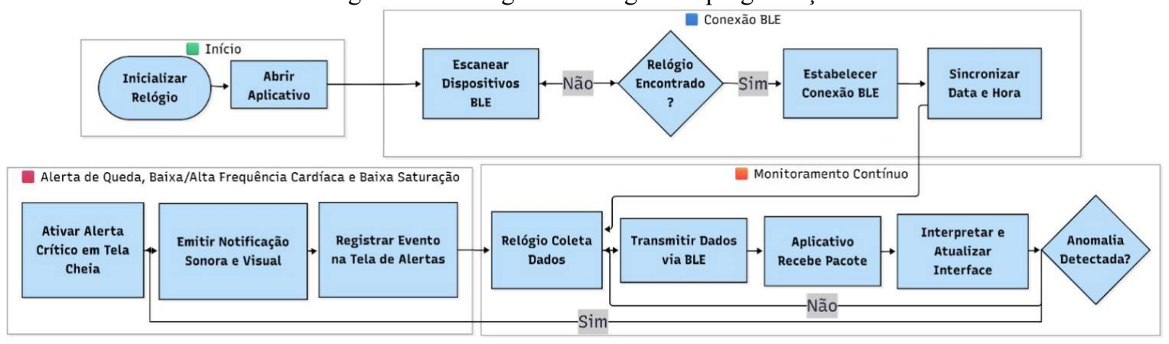
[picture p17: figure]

Fonte: Autoria própria (2026)

No firmware embarcado, a programação inicia com a configuração dos periféricos do protótipo, incluindo display, botões, sensores e comunicação Bluetooth Low Energy (BLE). Em seguida, o sistema passa a operar de forma contínua, realizando a leitura do acelerômetro MPU6050 e do sensor MAX30102. Os dados coletados são processados para obtenção de informações como frequência cardíaca, saturação de oxigênio, passos e possível queda. A comunicação entre relógio e aplicativo ocorre pelo BLE como informado acima, utilizando um serviço customizado para envio e recebimento de dados. O relógio transmite periodicamente ao celular, a leitura dos dados dos sensores. No sentido contrário, o aplicativo envia comandos ao dispositivo, permitindo uma comunicação bidirecional entre os sistemas.
O firmware também controla a interface gráfica do relógio por meio de uma lógica de estados, possibilitando a alternância entre telas de horário, dados de saúde, passos e configurações. Essa estrutura facilita a navegação por botões físicos e organiza melhor a atualização das informações no display. Além disso, o relógio recebe comandos enviados pelo aplicativo, lembretes e alertas configurados pelo usuário. Quando o relógio envia um sinal de queda, o aplicativo identifica o evento e dispara um alerta em tela cheia, com notificação sonora e visual, registrando a ocorrência na tela de alertas. Também foram implementados alertas personalizados para frequência cardíaca alta ou baixa e saturação de oxigênio fora dos limites definidos. Dessa forma, a programação do projeto foi dividida entre o firmware embarcado, responsável pela coleta e processamento inicial, e o aplicativo móvel, responsável pela visualização, gerenciamento de alertas e interação com o usuário.

11

### 3.1.4 Arquitetura do sistema

A arquitetura do sistema HAWK (Health Assistant Wearable for Care) foi concebida segundo um modelo distribuído em múltiplas camadas, com o objetivo de garantir modularidade, escalabilidade e clara separação de responsabilidades entre os componentes. O sistema é composto por três camadas principais: Sistema Embarcado, Backend em Nuvem, Aplicativo Mobile, conforme ilustrado na figura 9.

Figura 9 – Composição do Protótipo

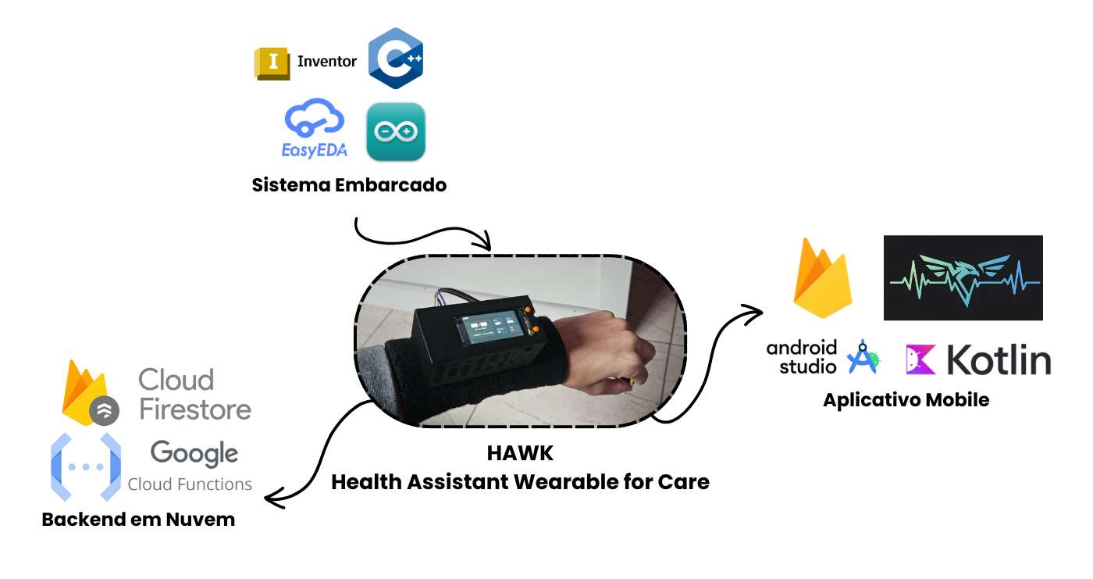
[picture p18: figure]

Fonte: Autoria própria (2026)

A camada de sistema embarcado corresponde ao dispositivo vestível responsável pela coleta e pré-processamento dos dados. O hardware é baseado em um microcontrolador ESP-32-S3, programado em linguagem C/C++. O projeto eletrônico foi desenvolvido por meio da ferramenta KiCad, possibilitando a construção do circuito e da placa de circuito impresso genérica (PCB), enquanto a modelagem mecânica do dispositivo foi realizada no Autodesk Inventor, permitindo a definição estrutural do encapsulamento físico do wearable. Essa camada é responsável pela aquisição de dados provenientes de sensores, processamento inicial dos sinais e comunicação com a infraestrutura em nuvem.
A camada de backend em nuvem foi definida com base na plataforma Firebase, utilizando o Cloud Firestore como banco de dados principal. Essa escolha se justifica pela integração direta com aplicações Android, suporte à sincronização em tempo real, facilidade de autenticação e possibilidade de acesso aos dados em diferentes dispositivos. No sistema proposto, o aplicativo móvel atua como gateway entre o dispositivo e a nuvem, recebendo os dados do dispositivo vestível por Bluetooth Low Energy, organizando as informações e enviando-as ao Firestore.
Os dados armazenados incluem passos, frequência cardíaca, saturação de oxigênio, quantidade de quedas, status de queda e data/hora da medição. Essa estrutura permite manter um histórico do usuário, gerar relatórios, registrar eventos críticos e disponibilizar as informações para cuidadores autorizados. A integração com o Firebase também possibilita expansão futura para autenticação com conta Google e acompanhamento remoto por múltiplos dispositivos.
Embora protocolos como Message Queuing Telemetry Transport (MQTT) sejam amplamente utilizados em aplicações IoT, optou-se pelo Firebase nesta etapa por sua maior simplicidade de integração

12

com o aplicativo Android e por oferecer recursos de banco de dados, autenticação e sincronização em uma única plataforma. Como perspectiva futura, a arquitetura pode ser expandida para incluir MQTT como camada de telemetria, especialmente em cenários com maior volume de dispositivos ou necessidade de comunicação IoT dedicada.

### 3.2 Validações do sistema e testes

Para validação do sistema cada sensor foi testado individualmente antes da integração ao sistema. O MAX30102 foi avaliado em leituras estáticas e dinâmicas para ajustar ganho, filtragem e cadência das amostras. O acelerômetro MPU6050 foi testado e analisado como era dado sua resposta a movimentos, incluindo simulações de passos e impactos para validar a lógica básica de detecção de queda.
Após a etapa dos sensores, iniciou-se a validação do firmware desenvolvido em C++ no Arduino IDE. Foram testados a inicialização dos módulos, a comunicação via I2C, o comportamento do sistema em leituras prolongadas e a integração das rotinas de economia de energia do ESP32-S3. Nesse momento também foi verificado se o fluxo lógico do programa seguia corretamente o comportamento descrito no fluxograma do projeto.
Com o protótipo montado, foram feitos testes funcionais simulando o uso real do dispositivo. Avaliaram-se a leitura de frequência cardíaca, oxigenação, passos e quedas. Foram realizadas caminhadas, movimentos aleatórios, simulações de quedas e comparações de batimentos cardíacos com oxímetros de dedo e um smartwatch comercial da fabricante Samsung. Também se testou a capacidade do protótipo de reiniciar e voltar ao funcionamento normal após interrupções de energia.
A comunicação bluetooth foi validada por meio do aplicativo gateway, verificando o pareamento, envio contínuo de dados, reconexão automática após perda de sinal e integridade dos pacotes transmitidos. Por fim, os testes incluíram o envio das informações para o backend, o armazenamento no firebase e a visualização no aplicativo, avaliando se os dados apareciam corretamente e se os alertas eram disparados conforme esperado.
Esses testes permitiram comprovar que o sistema opera de forma consistente desde a leitura das informações no dispositivo vestível até o armazenamento e visualização final no ambiente remoto, garantindo a confiabilidade necessária para o monitoramento geriátrico.

### 3.3 Custos do projeto

Os custos do projeto foram elaborados com base na soma dos custos diretos de materiais e dos custos estimados de mão de obra necessários para o desenvolvimento, concepção e implementação do protótipo. Na categoria de materiais, foram incluídos os componentes eletrônicos, módulos sensores, dispositivos de alimentação, elementos de interconexão, estrutura de montagem e ferramentas empregadas durante o desenvolvimento experimental.
Além dos custos físicos do protótipo, também foi considerada uma estimativa de mão de obra técnica especializada, contemplando profissionais com atuação em eletrônica, sistemas embarcados, desenvolvimento mobile e projeto mecânico. Os valores dos materiais foram obtidos por meio de compras realizadas em fornecedores nacionais e internacionais, enquanto os custos de mão de obra foram estimados a partir do valor-hora médio atribuído a cada perfil profissional. O quadro 1 reúne, de forma detalhada, os componentes empregados, suas quantidades e custos, além da estimativa de mão de obra envolvida no desenvolvimento do projeto.

13

Quadro 1 – Custos do projeto
Lista de componentes e custo do dispositivo
Componente | Quantidade | Preço | Total
Bateria Li-Ion 3,7V 1800 mAh | 3 | R$ 29,90 | R$ 89,70
TP4056 V2 USB-C Carregador BMS | 2 | R$ 12,00 | R$ 24,00
ESP32 C3 mini | 2 | R$ 47,00 | R$ 94,00
Regulador de tensão | 2 | R$ 9,90 | R$ 19,80
Acelerômetro | 4 | R$ 19,90 | R$ 79,60
Sensor de frequência cardíaca | 2 | R$ 29,90 | R$ 59,80
Sensor de pulso | 1 | R$ 32,90 | R$ 32,90
Display LCD TFT 1,6" | 1 | R$ 74,90 | R$ 74,90
Ferro de solda | 1 | R$ 38,90 | R$ 38,90
Kit Jumpers flexível | 4 | R$ 21,30 | R$ 85,20
T-Display S3 | 1 | R$ 150,90 | R$ 150,90
T-Display S3 com Case | 1 | R$ 231,92 | R$ 231,92
Placa padrão de circuito impresso | 20 | R$ 1,90 | R$ 38,00
Cabos Jumpers Rigido | 140 | R$ 0,19 | R$ 27,00
TPS63020 | 3 | R$ 17,00 | R$ 51,00
MAX30102 | 3 | R$ 11,00 | R$ 33,00
Total | | | R$ 1.130,62
Custo de mão de obra
Profissional | Quantidade (h) | Preço por hora | Valor total
Engenheiro Eletrônico | 140 | R$ 86,30 | R$ 12.082,00
Engenheiro de Software | 400 | R$ 91,23 | R$ 36.492,00
Engenheiro Mecânico | 100 | R$ 80,00 | R$ 8.000,00
Total | | | R$ 56.574,00
Fonte: Autoria própria (2026)

### 4 Resultados e discussão

O sistema desenvolvido resultou em um dispositivo vestível integrado composto por firmware embarcado em T-Display ESP32-S3 e aplicação móvel Android com personalização de perfil para cada usuário, comunicando-se por meio de Bluetooth Low Energy. O protótipo incorporou dois sensores principais: o MPU6050, responsável pela aquisição de aceleração tridimensional para análise de movimento, identificação de passos e detecção de quedas, e o MAX30102, utilizado para estimativa de frequência cardíaca e saturação de oxigênio.
Durante o desenvolvimento, foram realizados diversos testes práticos com o objetivo de ajustar e validar o comportamento funcional do sistema. Para a lógica de detecção de quedas, foram executadas dezenas de simulações controladas, variando os movimentos, posições de impacto e intensidade das quedas, até que fossem definidos parâmetros mais adequados para o sensor MPU6050. Esse processo permitiu calibrar os limiares utilizados pelo algoritmo, buscando melhorar a identificação de eventos reais e reduzir acionamentos indevidos causados por movimentos bruscos do usuário, o quadro 2 ilustra a matriz de confusão referente aos resultados dos testes.

14

Quadro 2 – Matriz de confusão
Valor previsto Valor verdadeiro | Queda real | Sem queda real
Detectou queda | 24 | 3
Não detectou queda | 6 | 27

Fonte: Autoria própria (2026)

A partir da matriz de confusão, observa-se que o sistema apresentou 24 verdadeiros positivos, 27 verdadeiros negativos, 3 falsos positivos e 6 falsos negativos. Com esses valores, obteve-se uma acurácia de 85%, sensibilidade de 80%, especificidade de 90% e precisão de 88,9%. Esses resultados indicam que o sistema possui bom desempenho na identificação de quedas, apresentando baixa ocorrência de falsos alarmes. Embora tenham ocorrido alguns casos não identificados, os resultados obtidos demonstram que o sistema apresenta desempenho satisfatório para a proposta inicial.
Também foram realizados testes relacionados ao monitoramento fisiológico com o sensor MAX30102. As medições de frequência cardíaca obtidas pelo protótipo foram comparadas com os valores apresentados por um oxímetro de dedo comercial, semelhante aos modelos utilizados em farmácias, e por um smartwatch Samsung, conforme quadro 3. Essa comparação teve como finalidade verificar a coerência das leituras obtidas pelo sistema desenvolvido, considerando que o protótipo possui caráter acadêmico e experimental, não sendo destinado ao uso clínico.

Quadro 3 – Testes monitoramento fisiológico

Teste | Condição do teste | Oxímetro de farmácia (bpm) | Relógio Samsung (bpm) | Protótipo com MAX30102 (bpm) | Diferença protótipo x oxímetro (bpm) | Diferença protótipo x Samsung (bpm) | SpO₂ no oxímetro de farmácia (%) | SpO₂ no relógio Samsung (%) | SpO₂ no protótipo com MAX30102 (%) | Diferença protótipo x oxímetro (%) | Diferença protótipo x Samsung (%)
1 | Repouso | 72 | 73 | 76 | 4 | 3 | 98 | 98 | 97 | 1 | 1
2 | Repouso | 65 | 65 | 65 | 0 | 0 | 99 | 99 | 97 | 2 | 2
3 | Repouso | 71 | 70 | 75 | 4 | 5 | 98 | 97 | 96 | 2 | 1
4 | Após movimentação leve | 89 | 85 | 89 | 0 | 4 | 98 | 97 | 96 | 2 | 1
5 | | 87 | 80 | 92 | 5 | 12 | 97 | 93 | 95 | 2 | 2
6 | | 89 | 94 | 94 | 5 | 0 | 97 | 97 | 95 | 2 | 2
7 | Após exercício | 108 | 111 | 126 | 18 | 15 | 96 | 95 | 94 | 2 | 1
8 | | 112 | 101 | 119 | 7 | 18 | 95 | 92 | 93 | 2 | 1
9 | | 104 | 105 | 111 | 7 | 6 | 96 | 95 | 94 | 2 | 1
10 | Repouso final | 76 | 79 | 81 | 5 | 2 | 98 | 97 | 96 | 2 | 1
Fonte: Autoria própria (2026)

15

A partir dos resultados obtidos, observa-se que o protótipo desenvolvido com o sensor MAX30102 apresentou comportamento coerente em relação às variações fisiológicas esperadas, acompanhando o aumento dos batimentos cardíacos após movimentação e exercício.
Além disso, foram conduzidos testes de caminhada para avaliar a resposta do sistema diante de movimentos periódicos do usuário, especialmente em relação à contagem de passos e à identificação de variações de aceleração. Esses ensaios contribuíram para observar o comportamento do sensor em situações próximas ao uso cotidiano do dispositivo vestível. Por fim, foram realizados testes de conexão, desconexão e reconexão entre o protótipo, o aplicativo Android e o serviço BLE, verificando a estabilidade da comunicação sem fio, a atualização dos dados na interface móvel e a retomada da transmissão após perda temporária de conexão.
A integração entre firmware, sensores, comunicação sem fio e aplicativo móvel demonstrou funcionamento coerente com a proposta do projeto, possibilitando o acompanhamento dos dados coletados pelo dispositivo em tempo real.

### 4.1 Comunicação BLE e protocolo de dados

A comunicação foi estruturada por meio de um serviço BLE customizado contendo três características: envio periódico de status, sincronização de data e hora e recebimento de comandos remotos. A característica de status opera com propriedades de leitura e notificação, transmitindo dados estruturados a cada 500 ms quando conectado.
O payload textual inclui horário, data, número de passos, estado de queda e valores instantâneos de aceleração nos eixos X, Y e Z. O tamanho médio da mensagem varia entre 70 e 120 bytes, mantendo-se dentro dos limites operacionais padrão de notificação BLE.
No aplicativo Android, o fluxo de comunicação envolve escaneamento, filtragem por nome do dispositivo, conexão GATT, descoberta de serviços, habilitação de notificações via escrita no descritor Client Characteristic Configuration Descriptor (CCCD) e processamento assíncrono de dados recebidos. A escrita nas características de sincronização e comando permite controle bidirecional do sistema.
Os testes demonstraram estabilidade no envio periódico de notificações e correta atualização dos dados na interface móvel, evidenciando consistência no protocolo implementado.

### 4.2 Processamento de movimento e detecção de queda

A detecção de queda foi implementada a partir do cálculo da magnitude da aceleração total, obtida pela raiz quadrada da soma dos quadrados das componentes de aceleração X, Y e Z, conforme mostrado na equação (1), a partir da leitura direta do acelerômetro MPU6050.

a = a
+ a

+ a

| (1)

No sistema desenvolvido, a aquisição desses dados ocorre em intervalos de aproximadamente 2 ms, resultando em uma taxa de amostragem próxima de 500 Hz.
O algoritmo de detecção utiliza uma lógica de validação baseada em dois eventos consecutivos: inicialmente, é identificada uma condição de “Alívio” quando a magnitude da aceleração total apresenta valor inferior a um limiar mínimo pré-definido. Em seguida, dentro de uma janela temporal limitada, é verificada a ocorrência de um pico de aceleração superior ao limiar de impacto. Caso ambas as condições sejam satisfeitas, o sistema interpreta o evento como uma possível queda.
Durante os testes experimentais figura 11, o sistema foi capaz de identificar corretamente eventos caracterizados por uma sequência típica de queda: redução abrupta da aceleração seguida de impacto

16

significativo. Entretanto, observou-se que movimentos bruscos, como agitação do braço ou impactos não associados a quedas reais, podem gerar ativações indevidas. Esse comportamento indica a necessidade de aprimoramentos futuros.
Figura 11 – Testes do MPU6050 - Queda

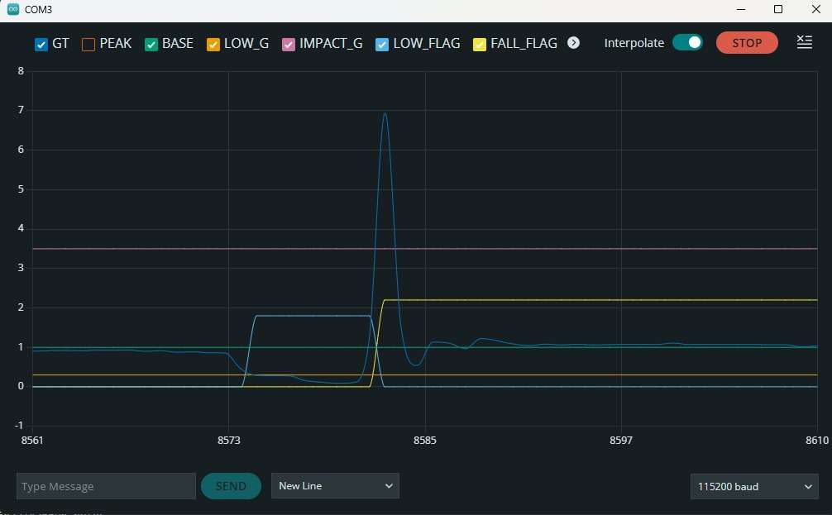
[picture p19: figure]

Fonte: Autoria Própria (2026)

A contagem de passos foi implementada com base na análise da variação dinâmica da aceleração total. A detecção de passos ocorre pela identificação de picos locais nesse sinal dinâmico, desde que atendam a limites mínimos e máximos de amplitude e respeitem um intervalo de tempo compatível com a cadência humana.
Essa abordagem permite diferenciar movimentos periódicos característicos da caminhada de movimentos aleatórios ou gesticulações, embora ainda não utilize calibração individual do usuário. Apesar de sua simplicidade, o método demonstrou desempenho satisfatório em condições normais de uso, com possibilidade de melhorias futuras por meio da adaptação dinâmica de limiares ou uso de aprendizado de máquina.

### 4.3 Monitoramento fisiológico com MAX30102

A figura 12 apresenta os dois principais métodos utilizados na fotopletismografia, a transmitância, em que a luz atravessa o tecido e é captada no lado oposto, e a reflectância, em que a luz refletida pelo tecido é captada pelo sensor posicionado no mesmo lado da emissão (CARMO JUNIOR; GALVÃO; BRITO FILHO, 2021).
O sensor de pulso e oximetria utilizado no projeto, baseado no módulo MAX30102, opera por meio da técnica de fotopletismografia utilizando o método de reflectância, figura 13 (configuração “b”), a qual consiste na medição das variações do volume sanguíneo em tecidos periféricos a partir da interação da luz com o corpo humano. Nesse método, o emissor e receptor ficam no mesmo lado, a variação do fluxo sanguíneo ao longo do ciclo cardíaco altera a quantidade de luz absorvida e refletida pelo tecido, permitindo a extração de informações fisiológicas relevantes.

17

Durante o ciclo cardíaco, a contração do coração (sístole) provoca aumento do volume sanguíneo nas artérias, elevando a absorção de luz e reduzindo a intensidade captada pelo fotodetector. Já na fase de relaxamento (diástole), ocorre o efeito inverso. Essas variações periódicas geram um sinal óptico pulsante, a partir do qual é possível identificar os batimentos cardíacos.
Além da medição da frequência cardíaca, o sensor utilizado também permite a estimativa da saturação de oxigênio no sangue (SpO₂), a partir da análise comparativa entre os sinais obtidos pelos LEDs vermelho e infravermelho. Essa técnica baseia-se na diferença de absorção da luz pela hemoglobina oxigenada e desoxigenada, possibilitando a inferência da porcentagem de oxigenação sanguínea.

Figura 12 – Métodos de fotopletismografia: (a) transmitância e (b) reflectância

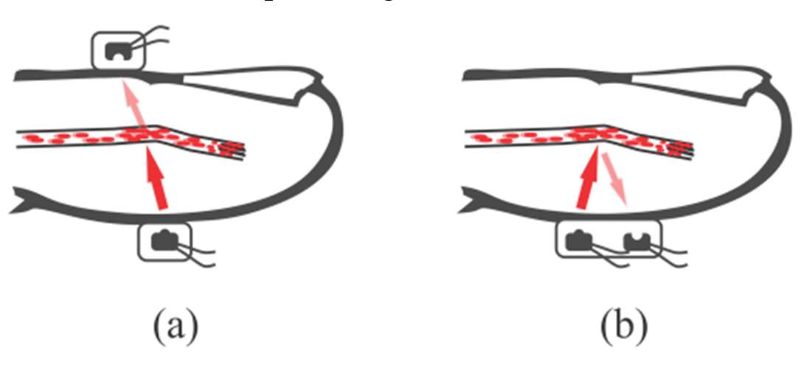
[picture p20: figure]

Fonte: Carmo Junior, Galvão e Brito Filho (2021).

A interface com o módulo MAX30102 foi realizada por meio da biblioteca desenvolvida pela SparkFun Electronics, que abstrai a comunicação via protocolo I2C e simplifica o acesso aos dados do sensor.
A inicialização é realizada em modo de comunicação rápida, sendo aplicada a configuração padrão do dispositivo. No projeto, adotou-se uma abordagem simplificada voltada à medição da frequência cardíaca, utilizando predominantemente o sinal infravermelho. O LED vermelho foi configurado com baixa intensidade de emissão.
A leitura do sinal ocorre de forma contínua, sendo os batimentos identificados por meio de um algoritmo de detecção de picos no sinal fotopletismográfico, conforme equação (2). A frequência cardíaca é calculada a partir do intervalo entre batimentos consecutivos e, para aumentar a estabilidade da medição, os valores obtidos são submetidos a uma média móvel simples, conforme equação (3). No sistema desenvolvido, foram utilizadas quatro amostras para o cálculo dessa média, garantindo um equilíbrio entre resposta rápida e suavização do sinal.

BPM =

60
∆t

(2)

Em que:
Δt = Tempo entre batimentos

BPMé =

1
N(BPM)

(3)

Em que:
N = Número de Amostras
BPM

= Valores medidos

18

Dessa forma, a configuração adotada prioriza simplicidade computacional e robustez na detecção dos batimentos cardíacos e da oximetria. Entretanto, ressalta-se que os dados obtidos pelo sistema não possuem validação clínica ou certificação médica, sendo destinados exclusivamente a fins de monitoramento e demonstração tecnológica, não devendo ser utilizados para diagnóstico ou acompanhamento médico profissional.

### 4.4 Interface embarcada e máquina de estados

A interface gráfica foi implementada através da biblioteca Arduino GFX Library, foi utilizado uma máquina de estados determinística, composta por seis estados principais e múltiplas telas secundárias. A navegação é realizada por botões físicos com distinção entre clique curto e longo, exigindo controle temporal baseado em contagem de milissegundos.
A atualização dinâmica de elementos visuais, como dados de aceleração e contagem de passos, ocorre de forma parcial, reduzindo processamento gráfico desnecessário. O controle de brilho é realizado por modulação por largura de pulso em quatro níveis discretos.
Essa estrutura evidencia integração entre controle de hardware, lógica temporal e renderização gráfica em ambiente embarcado com recursos limitados.
A figura 13 ilustra a interface da tela principal do protótipo.

Figura 13 – Interface

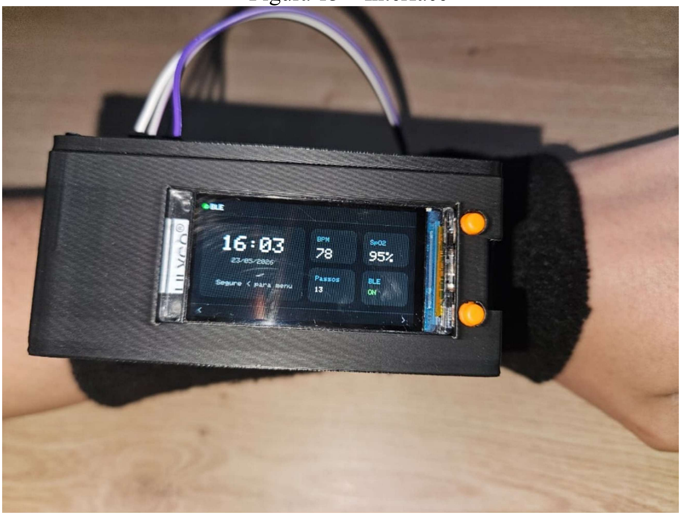
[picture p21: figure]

Fonte: Autoria Própria (2026)

### 4.5 Análise quantitativa da implementação

O firmware embarcado possui aproximadamente mil e quinhentas linhas de código organizadas em módulos funcionais. A estrutura inclui uma estrutura principal de dados, duas enumerações de estados, múltiplas funções especializadas e três callbacks BLE distintos.
A leitura do MPU6050 ocorre a aproximadamente 500 Hz, enquanto o envio de dados BLE ocorre a 2 transmissões por segundo. A atualização geral de dados ocorre em intervalo de 1 segundo. Essas taxas demonstram equilíbrio entre responsividade e consumo computacional.

19

A aplicação Android foi estruturada com arquitetura reativa, contendo repositório de comunicação BLE, ViewModel para gerenciamento de estado e interface implementada em Jetpack Compose. A comunicação é orientada a eventos e baseada em callbacks assíncronos do stack GATT.
Considerando o sistema completo, observa-se implementação integrada de sensores físicos, processamento em tempo real, protocolo BLE customizado, interface gráfica embarcada e aplicação móvel, caracterizando solução IoT funcional e coesa.

### 4.6 Aplicação móvel android

O aplicativo móvel desenvolvido para o projeto recebeu o nome TCC Hawk (Health Assistant Watch Kare), mantendo a identidade visual e conceitual do sistema como um todo. A escolha do nome Hawk, que em inglês significa “falcão”, está relacionada à ideia de vigilância, atenção constante e resposta rápida, características diretamente associadas à proposta do projeto. Assim como um falcão observa o ambiente com precisão, o aplicativo foi pensado para acompanhar continuamente as informações geradas pelo dispositivo vestível, permitindo que dados de saúde, movimento e alertas sejam visualizados de forma simples e objetiva pelo usuário ou responsável. Dessa forma, o nome não foi adotado apenas como identificação estética, mas como representação da função principal do sistema: monitorar, interpretar e alertar.
A criação do aplicativo Android foi necessária porque o dispositivo, por limitações físicas de tela, botões e processamento, não seria suficiente para apresentar todas as informações de forma clara. Embora o dispositivo vestível realize a leitura dos sensores e execute funções locais, como exibição de horário, detecção de movimento, alarmes e identificação de possível queda, o aplicativo assume o papel de interface principal para acompanhamento, configuração e análise dos dados. Por meio dele, o usuário consegue visualizar os batimentos cardíacos, passos, estado de movimento ou repouso, dados do acelerômetro, alertas registrados, cuidadores cadastrados e informações consolidadas em relatórios. Assim, o aplicativo amplia a usabilidade do protótipo, tornando o sistema mais acessível e adequado ao contexto de cuidado geriátrico.
O desenvolvimento foi realizado no Android Studio, por ser o ambiente oficial para criação de aplicações Android e por oferecer ferramentas completas de programação, depuração, emulação e integração com dispositivos físicos. A linguagem utilizada foi Kotlin, escolhida por ser moderna, segura e amplamente adotada no desenvolvimento Android atual. Para a construção da interface gráfica, foi utilizado Jetpack Compose, que permite criar telas de forma declarativa, facilitando a organização dos componentes visuais e a atualização dinâmica dos dados recebidos do relógio. Essa escolha foi importante porque o aplicativo precisava reagir em tempo real às informações enviadas por Bluetooth, atualizando cards, status e alertas sem exigir recarregamento manual da tela.
A interface do aplicativo foi organizada em telas principais, acessadas por uma barra inferior de navegação. A tela de painel principal (figura 14) apresenta o resumo diário do usuário, incluindo frequência cardíaca, quantidade de passos, tempo em movimento, tempo em repouso, dados do acelerômetro e estado da conexão com o relógio. Essa tela funciona como o centro de monitoramento do sistema, exibindo os dados mais importantes de maneira direta.

20

Figura 14 – Painel Principal

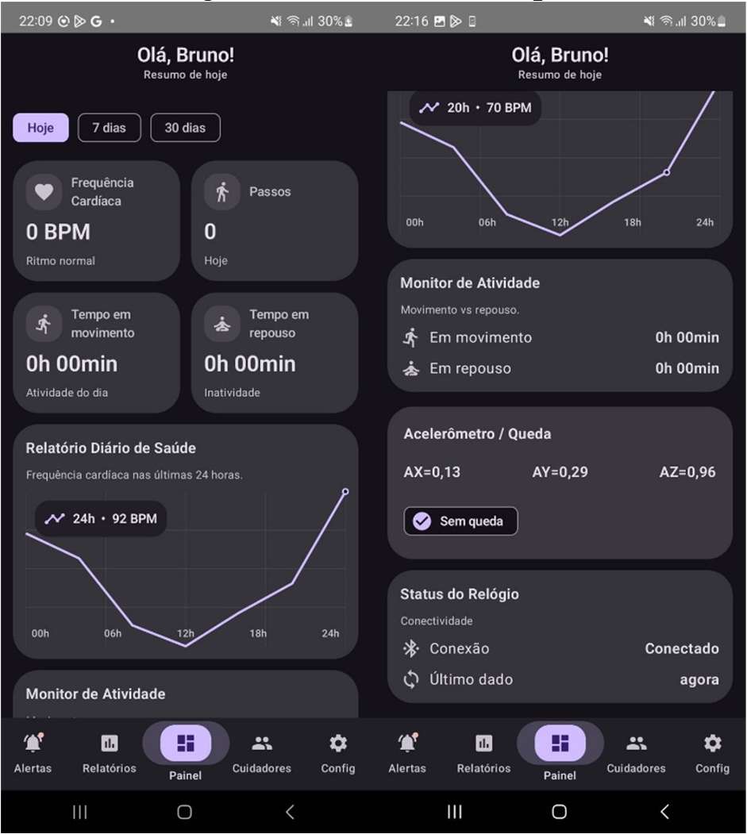
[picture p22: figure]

Fonte: Autoria Própria (2026)

A tela de alertas concentra eventos relevantes, como lembretes e possíveis quedas. Já a tela de relatórios foi planejada para consolidar informações em períodos de 24 horas, 7 dias e 30 dias, permitindo uma visão mais ampla da evolução dos dados. A tela de cuidadores representa a lógica de acompanhamento por terceiros, permitindo identificar responsáveis que poderiam receber notificações em caso de eventos críticos. Por fim, a área de configurações reúne ajustes e opções gerais do sistema.
A comunicação entre o aplicativo e o dispositivo foi implementada por Bluetooth Low Energy, tecnologia escolhida por apresentar baixo consumo energético e ser adequada para dispositivos vestíveis. No aplicativo, a conexão envolve escaneamento do dispositivo, identificação pelo nome configurado no dispositivo, conexão GATT, descoberta dos serviços BLE e habilitação de notificações por meio do descritor CCCD (Client Characteristic Configuration Descriptor). O dispositivo envia periodicamente um payload textual contendo informações como batimentos, saturação, passos, estado de queda e valores dos eixos do acelerômetro. O aplicativo interpreta esse payload, converte os dados recebidos para estruturas internas e atualiza a interface por meio de uma arquitetura reativa. Além disso, a comunicação também ocorre no sentido inverso, pois o celular envia ao dispositivo informações de sincronização, como horário e data, além de comandos relacionados a alarmes e lembretes.
A arquitetura interna do aplicativo foi separada em camadas para facilitar manutenção e organização. A camada de comunicação BLE é responsável por conectar, receber e enviar dados ao dispositivo. A camada de repositório centraliza o acesso aos dados e expõe fluxos de informação para o restante do aplicativo. A camada de ViewModel realiza o controle de estado das telas, transformando os dados brutos recebidos em informações prontas para exibição. A interface, construída com Jetpack Compose, apenas observa esses estados e atualiza os componentes visuais automaticamente. Essa separação evita que a lógica de bluetooth fique misturada com a interface gráfica, tornando o projeto mais limpo e escalável.
Durante os testes, também foi utilizado o aplicativo nRF Connect como ferramenta auxiliar de validação da comunicação BLE. Ele permitiu verificar se o dispositivo estava anunciando corretamente o serviço, se as características estavam disponíveis e se os pacotes de dados estavam sendo enviados pelo dispositivo. Essa etapa foi importante para diferenciar problemas do firmware, da conexão bluetooth e da

21

interface Android. Quando os dados apareciam corretamente no nRF Connect, mas não eram exibidos no aplicativo, a análise pôde ser direcionada para o parser, para o fluxo de estado e para os componentes da tela. Com isso, o processo de depuração tornou-se mais objetivo e eficiente.
O aplicativo também incorporou uma lógica de alertas para eventos relevantes. Os lembretes configurados pelo usuário podem ser enviados ao dispositivo e tratados no próprio celular. Para eventos de queda, o sistema utiliza o campo Q enviado pelo dispositivo. Quando o valor indica uma possível queda, o aplicativo atualiza o card do acelerômetro, registra o evento na tela de alertas e dispara uma notificação crítica em tela cheia (figura 15). Essa notificação foi configurada para utilizar som de alarme, vibração e prioridade elevada, buscando chamar a atenção do cuidador ou usuário mesmo em emergências.

Figura 15 – Alerta de Queda

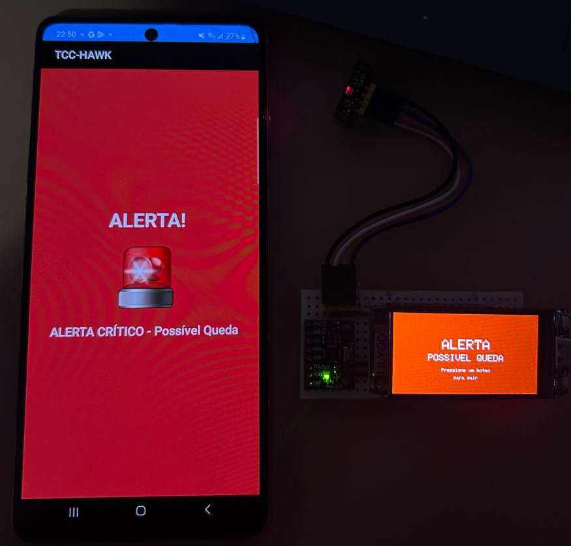
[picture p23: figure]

Fonte: Autoria Própria (2026)

Embora aplicativos comuns não tenham o mesmo nível de privilégio de alertas governamentais, como os utilizados pela Defesa Civil, a solução implementada aproxima esse comportamento por meio de recursos disponíveis no Android, como full-screen intent, canal de notificação de alta prioridade, vibração e uso de som de alarme.
O aplicativo também conta com alertas pré-programados para auxiliar na rotina de cuidados do usuário, incluindo lembretes de hidratação (figura 16), horário de medicação (figura 17), hora de dormir (figura 18) e alertas gerais. Esses lembretes foram implementados para facilitar o acompanhamento diário, permitindo que o cuidador ou o próprio usuário configure avisos recorrentes de acordo com as necessidades da pessoa monitorada. Cada tipo de alerta possui identificação visual própria, com mensagem, cor e símbolo correspondente, tornando a notificação mais intuitiva. Para garantir compatibilidade com o relógio, as mensagens enviadas ao dispositivo vestível são simplificadas, sem acentos ou caracteres especiais, enquanto no aplicativo móvel são exibidas de forma mais completa e amigável.

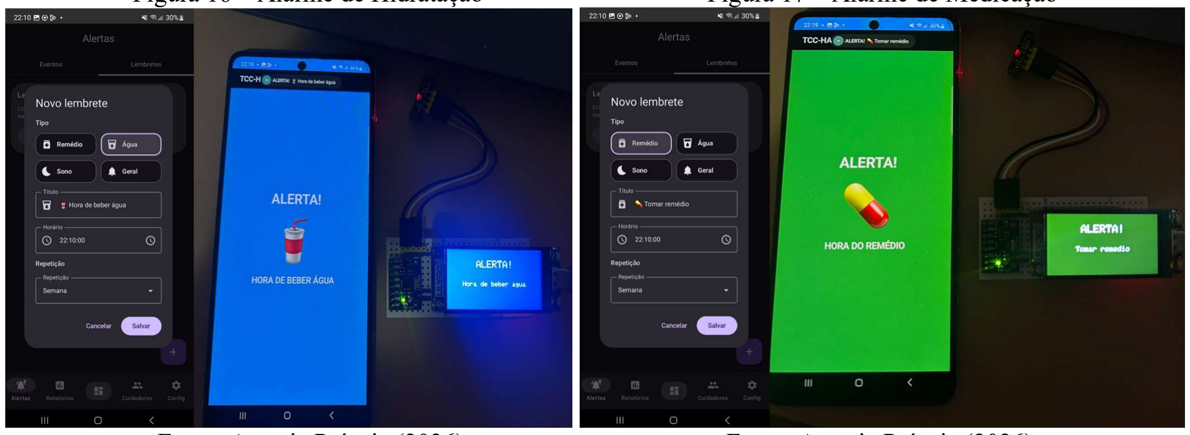
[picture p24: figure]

22

Figura 16 – Alarme de Hidratação | Figura 17 – Alarme de Medicação
Fonte: Autoria Própria (2026) | Fonte: Autoria Própria (2026)

Figura 18 – Alarme de Hora de Dormir

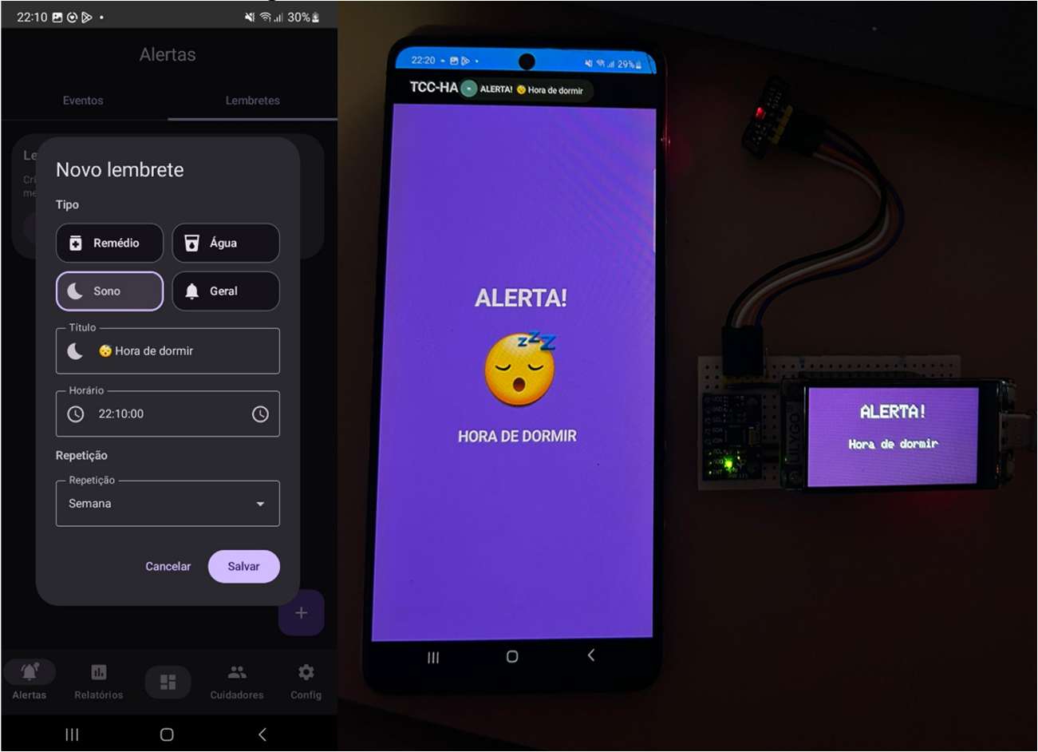
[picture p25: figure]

Fonte: Autoria Própria (2026)

De modo geral, o aplicativo Android é o elemento que transforma o protótipo vestível em um sistema de acompanhamento mais completo. Ele não apenas exibe os dados coletados, mas também organiza informações, envia comandos, registra eventos, melhora a experiência de uso e cria uma base para futuras expansões, como armazenamento em nuvem, geração automática de relatórios mensais e envio de informações para cuidadores ou profissionais de saúde. Com isso, a aplicação móvel deixa de ser apenas uma tela auxiliar e passa a compor a camada principal de interação entre o usuário, o dispositivo vestível e o sistema de cuidado proposto.

23

### 4.7 Limitações e perspectivas

Apesar da funcionalidade alcançada, o sistema apresenta limitações relevantes. O algoritmo de detecção de queda utiliza limiares fixos e não emprega aprendizado de máquina. A contagem de passos é simplificada e não calibrada individualmente. O módulo MAX30102 não passou por validação clínica, limitando sua aplicação a caráter experimental.
Como perspectiva futura, recomenda-se a realização de testes de usabilidade com usuários idosos e cuidadores, a fim de avaliar conforto, facilidade de uso, compreensão dos alertas, aceitação da interface e aderência ao uso contínuo. Essa etapa é relevante porque, conforme Moore et al. (2021), a efetividade de dispositivos vestíveis para adultos mais velhos está relacionada não apenas à precisão das medições, mas também à percepção de valor, simplicidade de uso e integração do dispositivo à rotina do usuário.

### 5 Considerações finais

Conclui-se que o protótipo desenvolvido atingiu o objetivo principal do trabalho ao apresentar uma solução vestível funcional para apoio ao cuidado geriátrico, integrando sensores, microcontrolador, comunicação sem fio e aplicação móvel em uma única plataforma. O dispositivo foi capaz de realizar leituras de sinais fisiológicos e dados de movimento, processar informações no sistema embarcado e transmiti-las para visualização no aplicativo, caracterizando uma solução IoT aplicada ao monitoramento de idosos.
Durante o desenvolvimento, foi possível validar a integração entre os principais componentes do sistema, incluindo o sensor MAX30102 para frequência cardíaca e oxigenação, o MPU6050 para análise de movimento e detecção de quedas, o ESP32-S3 como unidade de processamento e o aplicativo Android como interface de acompanhamento. Os testes realizados demonstraram estabilidade na comunicação BLE, funcionamento adequado das rotinas embarcadas e coerência na exibição dos dados coletados. Esses resultados evidenciam que o sistema possui potencial para contribuir com o acompanhamento remoto e com a identificação de situações de risco.
Ainda assim, o projeto deve ser compreendido como um protótipo experimental, não possuindo finalidade médica ou diagnóstica. As principais limitações envolvem a necessidade de maior precisão na detecção de quedas, redução de falsos positivos e negativos, validação clínica dos sensores fisiológicos e ampliação dos testes em condições reais de uso. Como continuidade do trabalho, sugere-se o aprimoramento dos algoritmos de processamento, a implementação de calibração personalizada, a integração com banco de dados em nuvem e o desenvolvimento de mecanismos de alerta para cuidadores e familiares, além da miniaturização do dispositivo. Com essas melhorias, a solução poderá evoluir para uma ferramenta mais completa, confiável e aplicável ao contexto do cuidado geriátrico.

24

Referências

ALMEIDA, A. N. P. et al. Aplicações de IoT em automação residencial para idosos e pessoas com mobilidade reduzida. BIUS – Boletim Informativo Unimotrisaúde em Sociogerontologia, v. 47, n. 41, 2024. Acesso em: 15 abril 2025.

BUSCARIOLLO, A. Inteligência artificial e automação residencial: tecnologia que transforma a vida de idosos. Centro Paula Souza – Inovações Tecnológicas, 2024. Disponível em: https://cprji.cps.sp.gov.br/inteligencia-artificial-e-automacao-residencial-tecnologia-que-transforma-a-vida-de-idosos/. Acesso em: 15 abril 2025.

CARMO JUNIOR, Francisco Augusto Alves do; GALVÃO, Renata Farias; BRITO FILHO, Francisco de Assis. Sistema para monitoramento não-invasivo da frequência cardíaca e oximetria de pulso por fotopletismografia. Anais do II ECOP - Pocket, UFERSA, Pau dos Ferros/RN, v. 5, 2021. ISSN 2526-7574. Disponível em: https://periodicos.ufersa.edu.br/index.php/ecop. Acesso em: 4 maio 2026.

DINIZ. et al. Internet of things gerontechnology for fall prevention in older adults: an integrative review. Acta Paul Enferm, v. 35, eAPE003142, 2022. Acesso em: 6 mar. 2025

DRYRUN. Finding the error in accelerometer readings. Arduino Forum, 4 jul. 2019. Disponível em: https://forum.arduino.cc/t/finding-the-error-in-accelerometer-readings/600015. Acesso em: 4 maio 2026.

FERREIRA. et al. Relação entre medidas fornecidas por smartwatches e a identificação de síndrome da fragilidade em idosos: revisão de escopo. Revista Brasileira de Geriatria e Gerontologia, v. 27, p. e230238, 2024. Acesso em: 26 mar. 2025

GODOY. et al. Inteligência artificial adaptada a idosos. Revista Interface Tecnológica, v. 18, n. 2, p. 208–218, 2021. Acesso em: 26 mar. 2025

GUESSE. et al. Smart Home: Inteligência Artificial com foco em conforto e segurança na melhor idade. Revista Científica Doctum Multidisciplinar, v. 1, n. 1, 2025. Disponível em: https://revista.doctum.edu.br/index.php/multi/article/view/617. Acesso em: 26 mar. 2025.

IBGE. Censo 2022: número de pessoas com 65 anos ou mais de idade cresceu 57,4% em 12 anos. Rio de Janeiro: IBGE, 2023. Disponível em: https://agenciadenoticias.ibge.gov.br/agencia-noticias/2012-agencia-de-noticias/noticias/38186-censo-2022-numero-de-pessoas-com-65-anos-ou-mais-de-idade-cresceu-57-4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. Acesso em: 25 set. 2025.

MARQUES, M. A.; DE CAMPOS, G. S.; DO NASCIMENTO, A. V. Protótipo de aparelho para detecção de quedas em idosos. Revista Kairós-Gerontologia, [S. l.], v. 25, n. 1, p. 227–249, 2022. DOI:

25

10.23925/2176-901X.2022v25i1p227-249. Disponível em: https://revistas.pucsp.br/index.php/kairos/article/view/57147. Acesso em: 24 nov. 2025.

MOORE, K. et al. Older adults' experiences with using wearable devices: qualitative systematic review and meta-synthesis. JMIR mHealth and uHealth, v. 9, n. 6, e23832, 2021. DOI: 10.2196/23832. Disponível em: https://pmc.ncbi.nlm.nih.gov/articles/PMC8212622/. Acesso em: 23 janeiro 2026.

ORGANIZAÇÃO MUNDIAL DA SAÚDE. Envelhecimento e saúde. Genebra: Organização Mundial da Saúde, 2024. Disponível em: https://www.who.int/news-room/fact-sheets/detail/ageing-and-health. Acesso em: 25 set. 2025

PAULISTA, G. et al. SmartCare: as novas tecnologias aplicadas no cuidado de idosos e PCD’s. 2022. Trabalho de Conclusão de Curso (Engenharia Elétrica) — Ânima Educação, Pouso Alegre, 13 dez. 2022. Disponível em: https://repositorio.animaeducacao.com.br/items/f74bc305-0621-41c3-b358-1b80f1ab5242. Acesso em: 24 nov. 2025.

POIANI, Jefferson Rodrigo; BRUNO, Diego Renan. AUTOMAÇÃO RESIDENCIAL: acessibilidade e inclusão. Revista Interface Tecnológica, v. 19, n. 1, p. 413–420, 2022. Disponível em: https://revista.fatectq.edu.br/interfacetecnologica/article/view/1394. Acesso em: 26 mar. 2025.

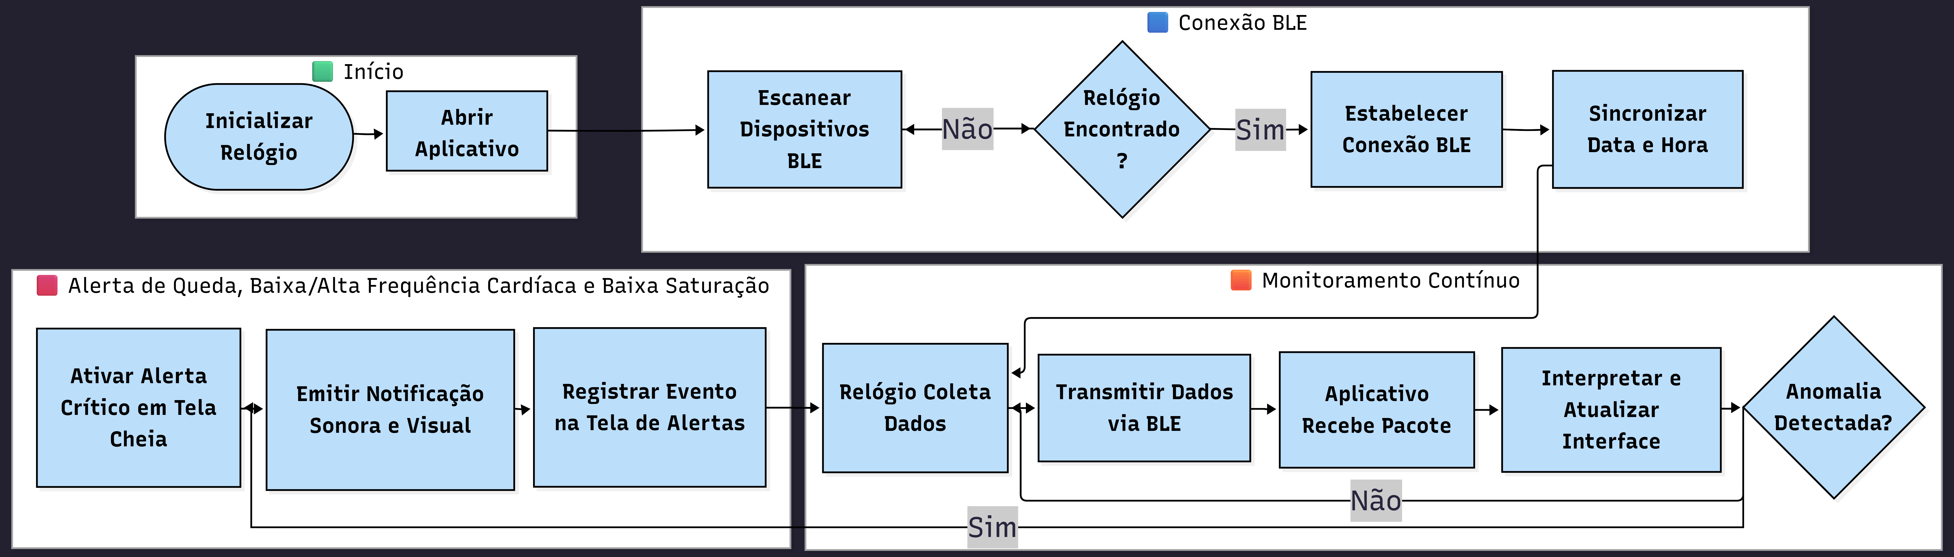
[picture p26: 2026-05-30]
docs/fluxogramas/logica_funcionamento.png

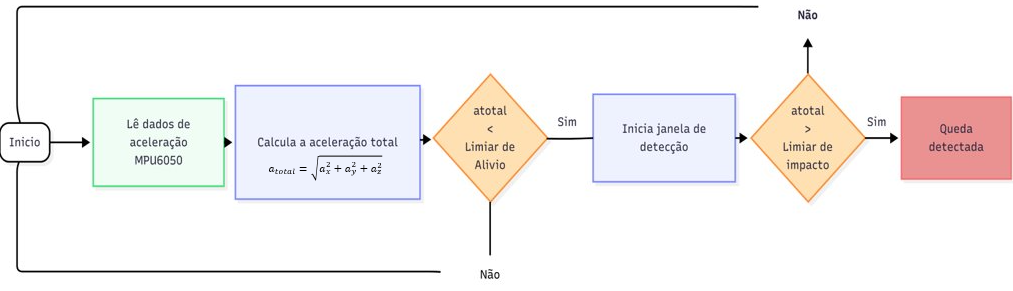
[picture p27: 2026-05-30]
docs/fluxogramas/detecção_queda.png

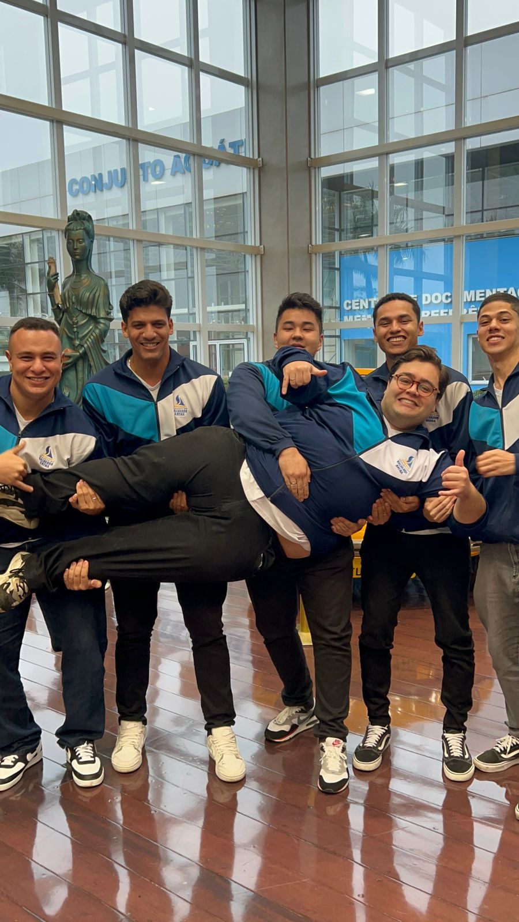
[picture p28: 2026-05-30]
docs/imagens/theMans.jpeg

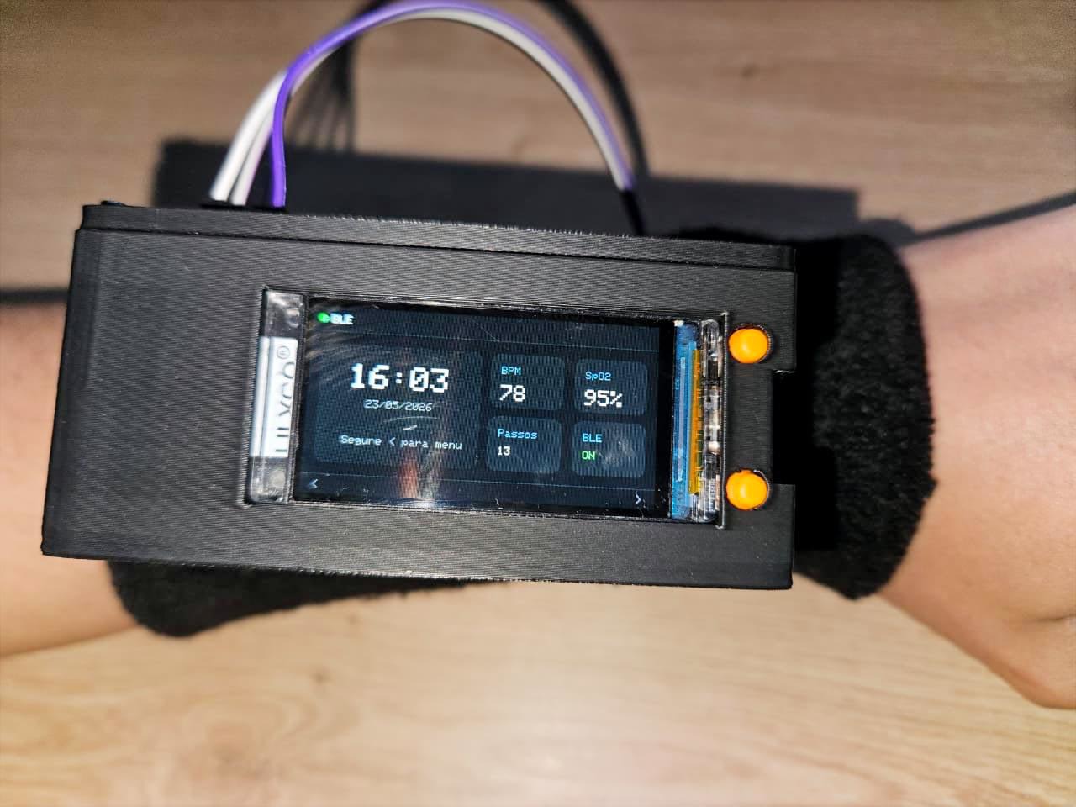
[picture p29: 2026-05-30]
docs/imagens/protótipo_final.jpg

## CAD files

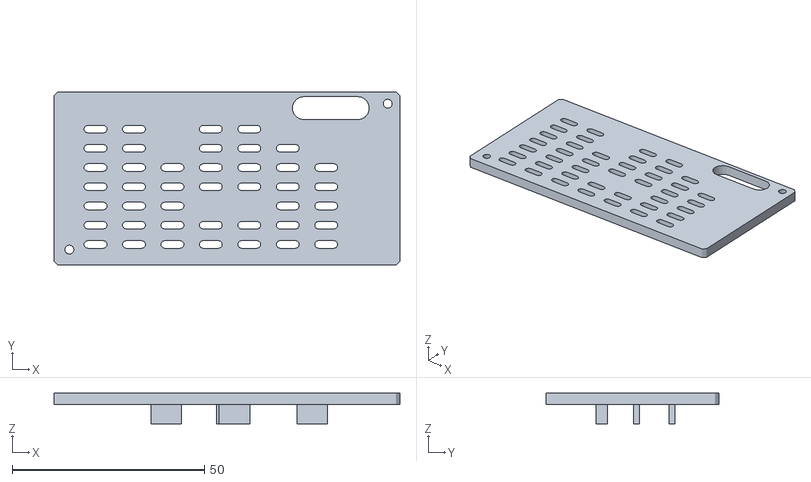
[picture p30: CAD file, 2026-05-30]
esquematicos/mecanico/tampa final.stl
90.0 x 45.0 x 8.00

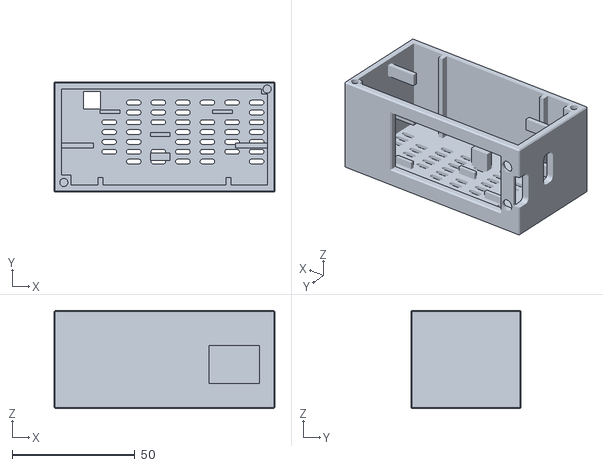
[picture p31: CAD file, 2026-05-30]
esquematicos/mecanico/carcaça final.stl
90.0 x 45.0 x 40.0

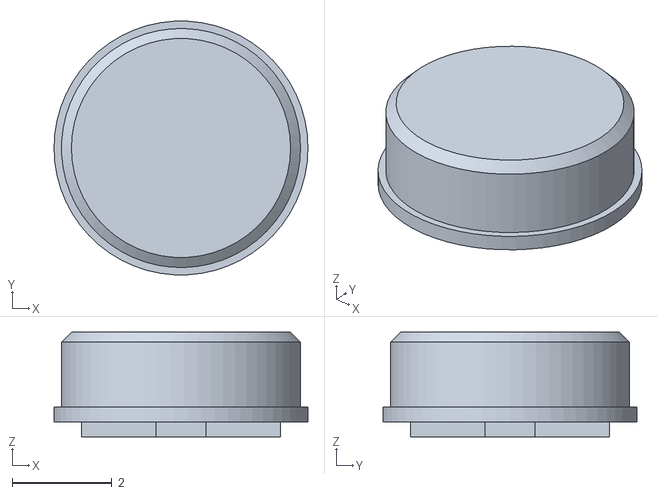
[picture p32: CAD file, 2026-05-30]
esquematicos/mecanico/botão final.stl
5.10 x 5.09 x 2.10

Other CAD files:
esquematicos/mecanico/Montagem_final.iam
esquematicos/mecanico/OldVersions/carcaça final.0017.ipt
esquematicos/mecanico/OldVersions/montagem_final_v2.0001.iam
esquematicos/mecanico/OldVersions/tampa final.0012.ipt
esquematicos/mecanico/botão final.ipt
esquematicos/mecanico/carcaça final.ipt
esquematicos/mecanico/montagem_final_v2.iam
esquematicos/mecanico/tampa final.ipt

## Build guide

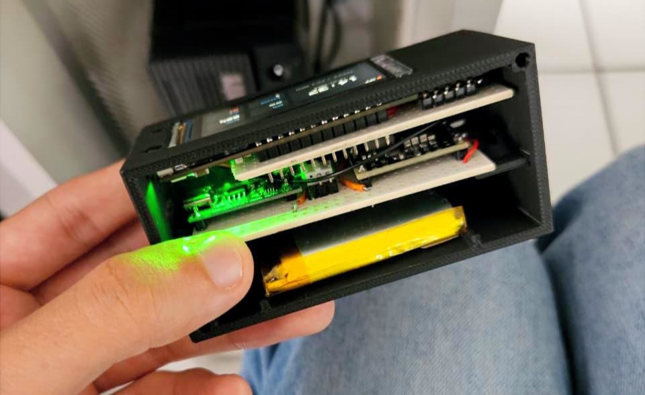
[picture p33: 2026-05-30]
docs/imagens/montagem_protótipo.jpg

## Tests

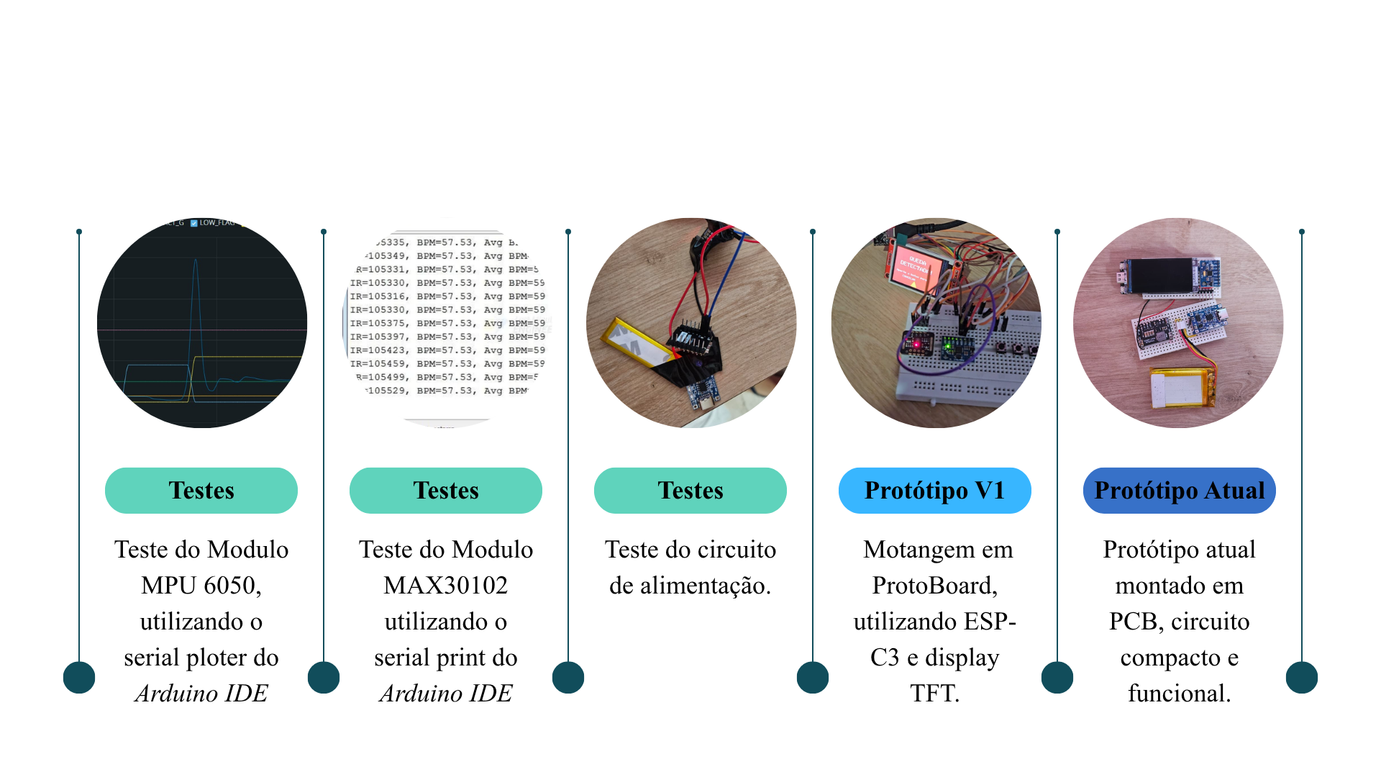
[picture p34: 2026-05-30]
docs/imagens/testes.png

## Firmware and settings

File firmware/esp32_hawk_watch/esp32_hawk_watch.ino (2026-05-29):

#include <MAX30105.h>
#include <Arduino_GFX_Library.h>
#include <BLEDevice.h>
#include <BLEServer.h>
#include <BLEUtils.h>
#include <BLE2902.h>
#include <Wire.h>
#include <math.h>
#include "heartRate.h"
#include "spo2_algorithm.h"
#include "alerts.h"

#define GFX_BL 38
#define LCD_POWER 15
#define BTN_LEFT  0
#define BTN_RIGHT 14
#define MPU_ADDR 0x68
#define I2C_SDA 18
#define I2C_SCL 17

// =============================
// AGENDAMENTO DE ALERTAS (BLE)
// =============================
#define MAX_SCHEDULED_ALERTS 16

struct ScheduledAlert {
  AlertItem alert;
  uint8_t hour;
  uint8_t minute;
  bool fired;            
  bool valid;
};

static ScheduledAlert scheduledAlerts[MAX_SCHEDULED_ALERTS];
static int scheduledCount = 0;

Arduino_DataBus *bus = new Arduino_ESP32PAR8Q(
  7, 6, 8, 9,
  39, 40, 41, 42, 45, 46, 47, 48
);

Arduino_GFX *gfx = new Arduino_ST7789(
  bus,
  5,
  1,
  true,
  170,
  320,
  35,
  0,
  35,
  0
);

// ==========================
// MAX30102 runtime 
// ==========================
MAX30105 particleSensor;
bool maxOK = false;

const byte RATE_SIZE = 4;
byte rates[RATE_SIZE] = {0};
byte rateSpot = 0;
long lastBeat = 0;

float beatsPerMinute = 0;
int beatAvg = 0;
long irValue = 0;

int lastAlertMinuteChecked = -1;
bool fingerPresent = false;
int currentDay = 1;
int currentMonth = 1;
int currentYear = 2026;

unsigned long lastFingerSeen = 0;

float bpmFiltered = 0.0f;
float spo2Filtered = 0.0f;

void triggerLocalAlert(AlertType type, unsigned long duration, const String &message) {
  AlertItem item;
  item.type = type;
  item.duration = duration;
  item.message = message;
  enqueueAlert(item);
}

// ==========================
// BLE
// ==========================
#define DEVICE_NAME "HAWK-WATCH"

static BLEUUID SERVICE_UUID("7E400001-8F42-4A7A-BB6F-112233445566");
static BLEUUID STATUS_UUID ("7E400002-8F42-4A7A-BB6F-112233445566");
static BLEUUID SYNC_UUID   ("7E400003-8F42-4A7A-BB6F-112233445566");
static BLEUUID CMD_UUID    ("7E400004-8F42-4A7A-BB6F-112233445566");

BLEServer *pServer = nullptr;
BLEService *pService = nullptr;
BLECharacteristic *pStatusChar = nullptr;
BLECharacteristic *pSyncChar = nullptr;
BLECharacteristic *pCmdChar = nullptr;

bool bleConnected = false;
unsigned long lastBLESend = 0;

bool timeSynced = false;
unsigned long lastTimeUpdate = 0;
int currentHour = 0;
int currentMinute = 0;
int currentSecond = 0;

// ==========================
// BEACON PROXIMITY
// ==========================
BLEScan *pBLEScan = nullptr;

String nearestBeaconName = "Nenhum";
int nearestBeaconRSSI = -999;
float nearestBeaconDist = 0.0f;

const int BEACON_SCAN_TIME = 1;
const int BEACON_TX_POWER = -71;
const float BEACON_N = 3.1f;

unsigned long lastBeaconScan = 0;
bool scanRunning = false;

// ==========================
// CORES
// ==========================
#define BG_COLOR      0x0841
#define TOP_BG        0x1082
#define CARD_1        0x2104
#define CARD_2        0x2945
#define LINE_COLOR    0x39C7
#define TXT_WHITE     0xFFFF
#define TXT_SOFT      0xCE79
#define TXT_CYAN      0x867D
#define TXT_CYAN2     0x8FDF
#define OK_GREEN      0x07E0
#define WARN_ORANGE   0xFD20
#define ALERT_RED     0xF800
#define FLASH_BLUE    0x01CF
#define MENU_HL       0x03EF

const int SCREEN_W = 320;
const int SCREEN_H = 170;

// ==========================
// DADOS
// ==========================
struct WatchData {
  String hora = "00:00";
  String data = "01/01/2000";
  int bpm = 0;
  int spo2 = 0; 
  int passos = 0;
  float ax = 0.0, ay = 0.0, az = 1.0;
  float tempMPU = 0.0f; 
  bool ble = false, queda = false, dedo = false;
  String aparelho = "Aguardando";
  String sync = "Nao sincronizado";
  
};
#define MAX_BUF_LEN 100
uint32_t irBuffer[MAX_BUF_LEN];
uint32_t redBuffer[MAX_BUF_LEN];
int32_t bufferLength = MAX_BUF_LEN;

int32_t spo2Calc = 0;
int8_t validSPO2 = 0;
int32_t heartRateCalc = 0;
int8_t validHeartRate = 0;

int maxSampleIndex = 0;
bool spo2BufferReady = false;
unsigned long lastMAXCalc = 0;

WatchData dados;

AlertItem currentAlert;
bool remoteAlertActive = false;
unsigned long remoteAlertUntil = 0;

// ==========================
// MPU runtime
// ==========================
bool mpuOK = false;
unsigned long lastMPURead = 0;
unsigned long lastStepTime = 0;
unsigned long fallUntil = 0;
volatile bool uiNeedsRefresh = false;
float lastMotionMetric = 0.0;
float tempMPU = 0.0f;

// ==========================
// PASSOS - runtime
// ==========================
float stepAccMag = 1.0f;
float stepAccFiltered = 1.0f;
float stepDcEstimate = 1.0f;
float stepDynamic = 0.0f;

float stepS0 = 0.0f;
float stepS1 = 0.0f;
float stepS2 = 0.0f;

// ajuste fino
const float STEP_LPF_ALPHA = 0.20f;
const float STEP_DC_ALPHA  = 0.03f;

const float STEP_MIN_PEAK  = 0.02f;
const float STEP_MAX_PEAK  = 0.32f;

const unsigned long STEP_MIN_INTERVAL = 500;
const unsigned long STEP_MAX_INTERVAL = 1400;
unsigned long lastValidPeakTime = 0;

float totalAccG = 1.0f;

float FALL_LOW_G = 0.4f;
float FALL_IMPACT_G = 3.0f;
unsigned long FALL_WINDOW_MS = 1800;
unsigned long FALL_ALERT_MS = 4000;

bool lowGDetected = false;
unsigned long lowGTs = 0;
float impactPeakG = 0.0f;
unsigned long impactPeakTs = 0;

// ==========================
// ESTADOS
// ==========================
enum AppState {
  STATE_WATCH,
  STATE_MENU,
  STATE_BRIGHTNESS,
  STATE_MEASURE,
  STATE_ALERT_FALL,
  STATE_REMOTE_ALERT,
  STATE_ABOUT
};
AppState appState = STATE_WATCH;

enum Screen {
  SCREEN_HOME = 0,
  SCREEN_HEALTH,
  SCREEN_MOTION,
  SCREEN_CONNECTION
};
Screen currentScreen = SCREEN_HOME;

// ==========================
// MENU
// ==========================
const char* menuItems[] = {
  "Voltar",
  "Brilho",
  "Medicao",
  "Simular queda",
  "Sobre"
};
const int menuCount = 5;
int menuIndex = 0;

// ==========================
// BRILHO
// ==========================
int brightnessIndex = 3;
const int brightnessLevels[] = {64, 128, 192, 255};

// ==========================
// BOTÕES
// ==========================
bool lastLeftState = HIGH;
bool lastRightState = HIGH;
unsigned long lastDebounce = 0;
unsigned long leftPressStart = 0;
unsigned long rightPressStart = 0;
bool leftLongHandled = false;
bool rightLongHandled = false;

const unsigned long debounceDelay = 120;
const unsigned long longPressTime = 650;

// ==========================
// TEXTO
// ==========================
void resetText() {
  gfx->setFont();
  gfx->setTextWrap(false);
  gfx->setTextSize(1);
}

void text(int x, int y, const String &s, uint16_t color, uint8_t size = 1) {
  resetText();
  gfx->setTextColor(color);
  gfx->setTextSize(size);
  gfx->setCursor(x, y);
  gfx->print(s);
}

void textCenter(int cx, int y, const String &s, uint16_t color, uint8_t size = 1) {
  resetText();
  gfx->setTextColor(color);
  gfx->setTextSize(size);
  int w = s.length() * 6 * size;
  int x = cx - (w / 2);
  gfx->setCursor(x, y);
  gfx->print(s);
}

// ==========================
// ELEMENTOS
// ==========================
void card(int x, int y, int w, int h, uint16_t color) {
  gfx->fillRoundRect(x, y, w, h, 8, color);
}

void drawBattery(int x, int y, int percent) {
  gfx->drawRoundRect(x, y, 24, 10, 2, TXT_WHITE);
  gfx->fillRect(x + 24, y + 3, 2, 4, TXT_WHITE);

  int fill = map(percent, 0, 100, 0, 20);
  if (fill < 0) fill = 0;
  if (fill > 20) fill = 20;

  uint16_t c = OK_GREEN;
  if (percent <= 50) c = WARN_ORANGE;
  if (percent <= 20) c = ALERT_RED;
  gfx->fillRoundRect(x + 2, y + 2, fill, 6, 2, c);
}

void drawMiniBar(int x, int y, int w, int h, int value, int maxValue, uint16_t color) {
  gfx->drawRoundRect(x, y, w, h, 4, LINE_COLOR);
  int fill = map(value, 0, maxValue, 0, w - 4);
  if (fill < 0) fill = 0;
  if (fill > w - 4) fill = w - 4;
  gfx->fillRoundRect(x + 2, y + 2, fill, h - 4, 3, color);
}

void drawPill(int x, int y, const String &txt, uint16_t bg, uint16_t fg) {
  int w = 20 + txt.length() * 6;
  if (w < 42) w = 42;
  gfx->fillRoundRect(x, y, w, 16, 7, bg);
  textCenter(x + w / 2, y + 5, txt, fg, 1);
}

void drawTopBar() {
  gfx->fillRect(0, 0, SCREEN_W, 22, TOP_BG);
  gfx->drawFastHLine(0, 22, SCREEN_W, LINE_COLOR);

  gfx->fillCircle(10, 11, 3, dados.ble ? OK_GREEN : WARN_ORANGE);
  text(18, 8, dados.ble ? "BLE" : "OFF", TXT_WHITE, 1);
}

void drawFooter(const String &leftTxt, const String &rightTxt) {
  gfx->drawFastHLine(0, 152, SCREEN_W, LINE_COLOR);
  text(10, 158, leftTxt, TXT_SOFT, 1);
  text(302, 158, rightTxt, TXT_SOFT, 1);
}

void drawFooterCenter(const String &middleTxt) {
  gfx->drawFastHLine(0, 152, SCREEN_W, LINE_COLOR);
  text(10, 158, "<", TXT_SOFT, 1);
  textCenter(160, 158, middleTxt, TXT_SOFT, 1);
  text(302, 158, ">", TXT_SOFT, 1);
}

void drawSectionTitle(const String &title) {
  text(10, 28, title, TXT_CYAN2, 2);
}

void transitionFlash() {
  gfx->fillRect(0, 22, SCREEN_W, 130, FLASH_BLUE);
  delay(10);
}

void applyBrightness() {
  ledcWrite(GFX_BL, brightnessLevels[brightnessIndex]);
}

// ==========================
// MPU6050 
// ==========================
void mpuWrite(uint8_t reg, uint8_t value) {
  Wire.beginTransmission(MPU_ADDR);
  Wire.write(reg);
  Wire.write(value);
  Wire.endTransmission();
}

bool mpuReadBytes(uint8_t reg, uint8_t count, uint8_t *dest) {
  Wire.beginTransmission(MPU_ADDR);
  Wire.write(reg);
  if (Wire.endTransmission(false) != 0) return false;
  uint8_t received = Wire.requestFrom(MPU_ADDR, count);
  if (received != count) return false;
  for (uint8_t i = 0; i < count; i++) {
    dest[i] = Wire.read();
  }
  return true;
}

bool initMPU6050() {
  delay(50);
  uint8_t whoami = 0;
  if (!mpuReadBytes(0x75, 1, &whoami)) return false;
  if (whoami != 0x68 && whoami != 0x70) return false;

  mpuWrite(0x6B, 0x00);
  delay(10);

  mpuWrite(0x1C, 0x08);
  delay(10);

  mpuWrite(0x1B, 0x00);
  delay(10);
  mpuWrite(0x1A, 0x01);
  delay(10);

  return true;
}

float readMPUTemperature() {
  uint8_t raw[2];
  if (!mpuReadBytes(0x41, 2, raw)) {
    return -999.0;
  }

  int16_t tempRaw = (int16_t)((raw[0] << 8) | raw[1]);
  float tempC = (tempRaw / 340.0f) + 36.53f;

  return tempC;
}

void updateStepCounter(float ax, float ay, float az) {
  stepAccMag = sqrtf(ax * ax + ay * ay + az * az);
  stepAccFiltered = (STEP_LPF_ALPHA * stepAccMag) +
                    ((1.0f - STEP_LPF_ALPHA) * stepAccFiltered);
  stepDcEstimate = (STEP_DC_ALPHA * stepAccFiltered) +
                   ((1.0f - STEP_DC_ALPHA) * stepDcEstimate);
  stepDynamic = stepAccFiltered - stepDcEstimate;

  stepS0 = stepS1;
  stepS1 = stepS2;
  stepS2 = stepDynamic;

  unsigned long now = millis();
  bool isPeak = (stepS1 > stepS0) &&
                (stepS1 > stepS2) &&
                (stepS1 >= STEP_MIN_PEAK) &&
                (stepS1 <= STEP_MAX_PEAK);
  if (!isPeak) return;

  if (lastValidPeakTime == 0) {
    lastValidPeakTime = now;
    return;
  }

  unsigned long dt = now - lastValidPeakTime;

  if (dt >= STEP_MIN_INTERVAL && dt <= STEP_MAX_INTERVAL) {
    dados.passos++;
    lastStepTime = now;
  }

  lastValidPeakTime = now;
}

void updateMPUData() {
  if (millis() - lastMPURead < 2) return;
  lastMPURead = millis();

  uint8_t raw[6];
  if (!mpuReadBytes(0x3B, 6, raw)) {
    mpuOK = false;
    return;
  }

  mpuOK = true;

  int16_t axRaw = (int16_t)((raw[0] << 8) | raw[1]);
  int16_t ayRaw = (int16_t)((raw[2] << 8) | raw[3]);
  int16_t azRaw = (int16_t)((raw[4] << 8) | raw[5]);
  
  dados.ax = axRaw / 8192.0f;
  dados.ay = ayRaw / 8192.0f;
  dados.az = azRaw / 8192.0f;

  dados.tempMPU = readMPUTemperature();
  
  totalAccG = sqrtf(
    dados.ax * dados.ax +
    dados.ay * dados.ay +
    dados.az * dados.az
  );
  
  if (totalAccG > impactPeakG) {
    impactPeakG = totalAccG;
    impactPeakTs = millis();
  }

  if (millis() - impactPeakTs > 150) {
    impactPeakG = totalAccG;
  }

  updateStepCounter(dados.ax, dados.ay, dados.az);
  
  if (!lowGDetected && totalAccG < FALL_LOW_G) {
    lowGDetected = true;
    lowGTs = millis();
  }

  if (lowGDetected && (millis() - lowGTs > FALL_WINDOW_MS)) {
    lowGDetected = false;
  }

  if (lowGDetected && impactPeakG > FALL_IMPACT_G) {
    dados.queda = true;
    fallUntil = millis() + FALL_ALERT_MS;
    lowGDetected = false;
  }

  if (dados.queda && millis() > fallUntil) {
    dados.queda = false;
  }
}


// ==========================
// MAX30102 
// ==========================
bool initMAX30102() {
  if (!particleSensor.begin(Wire, I2C_SPEED_FAST)) {
    return false;
  }

  particleSensor.setup(); 
  particleSensor.setPulseAmplitudeRed(0x20); // LED Vermelho
  particleSensor.setPulseAmplitudeIR(0x30);  // LED Infravermelho
  particleSensor.setPulseAmplitudeGreen(0);

  beatsPerMinute = 0;
  beatAvg = 0;
  rateSpot = 0;
  lastBeat = 0;
  
  maxSampleIndex = 0;
  spo2BufferReady = false;

  dados.bpm = 0;
  dados.spo2 = 0;
  dados.dedo = false;

  return true;
}

void updateMAX30102() {
  long irValue = particleSensor.getIR();
  long redValue = particleSensor.getRed();

  static unsigned long lastDebug = 0;
  if (millis() - lastDebug > 500) {
    lastDebug = millis();
  }

  if (irValue < 50000) {
    dados.dedo = false;
    dados.bpm = 0;
    dados.spo2 = 0;
    
    maxSampleIndex = 0;
    spo2BufferReady = false;
    return;
  }

  dados.dedo = true;

  if (maxSampleIndex < MAX_BUF_LEN) {
    irBuffer[maxSampleIndex] = irValue;
    redBuffer[maxSampleIndex] = redValue;
    maxSampleIndex++;
  }

  if (maxSampleIndex >= MAX_BUF_LEN) {
    spo2BufferReady = true;
    for (int i = 25; i < 100; i++) {
      irBuffer[i - 25] = irBuffer[i];
      redBuffer[i - 25] = redBuffer[i];
    }
    maxSampleIndex = 75; 
  }

  if (spo2BufferReady && millis() - lastMAXCalc > 1000) {
    lastMAXCalc = millis();
    
    maxim_heart_rate_and_oxygen_saturation(
      irBuffer, bufferLength, redBuffer,
      &spo2Calc, &validSPO2, &heartRateCalc, &validHeartRate
    );

    if (validSPO2 && spo2Calc >= 85 && spo2Calc <= 99) {
      if (dados.spo2 == 0) {
        dados.spo2 = spo2Calc; 
      } else {
        dados.spo2 = (dados.spo2 * 0.8) + (spo2Calc * 0.2);
      }
    }

    if (validHeartRate && heartRateCalc > 40 && heartRateCalc < 200) {
      if (dados.bpm == 0) {
        dados.bpm = heartRateCalc;
      } else {
        int diferenca = abs(heartRateCalc - dados.bpm);
        
        if (diferenca < 25) { 
          dados.bpm = (dados.bpm * 0.80) + (heartRateCalc * 0.20);
        }
      }
    }
  }
}
// ==========================
// BLE HELPERS
// ==========================
String makeStatusPayload() {
  char buffer[256];
  snprintf(buffer, sizeof(buffer),
      "H:%s;"
      "D:%s;"
      "BPM:%d;"
      "SPO2:%d;"
      "P:%d;"
      "Q:%d;"
      "X:%.2f;"
      "Y:%.2f;"
      "Z:%.2f;"
      "MPU:%d;"
      "MAX:%d;"
      "F:%d;",
      dados.hora.c_str(),
      dados.data.c_str(),
      dados.bpm,
      dados.spo2,
      dados.passos,
      dados.queda ? 1 : 0,
      dados.ax,
      dados.ay,
      dados.az,
      mpuOK ? 1 : 0,
      maxOK ? 1 : 0,
      dados.dedo ? 1 : 0
  );
  return String(buffer);
}

void updateDateFromSyncString(const String &syncStr) {
  if (syncStr.length() < 19) return;

  int y = syncStr.substring(0, 4).toInt();
  int m = syncStr.substring(5, 7).toInt();
  int d = syncStr.substring(8, 10).toInt();
  int h = syncStr.substring(11, 13).toInt();
  int min = syncStr.substring(14, 16).toInt();
  int ss = syncStr.substring(17, 19).toInt();

  currentYear = y;
  currentMonth = m;
  currentDay = d;
  currentHour = h;
  currentMinute = min;
  currentSecond = ss;
  char horaBuffer[6];
  char dataBuffer[11];
  sprintf(horaBuffer, "%02d:%02d", h, min);
  sprintf(dataBuffer, "%02d/%02d/%04d", d, m, y);

  dados.hora = String(horaBuffer);
  dados.data = String(dataBuffer);

  timeSynced = true;
  lastTimeUpdate = millis();
  dados.sync = "Sincronizado";
}

void updateRtcFromMillis() {
  if (!timeSynced) return;
  unsigned long now = millis();
  unsigned long elapsed = now - lastTimeUpdate;
  if (elapsed < 1000) return;

  unsigned long secondsPassed = elapsed / 1000;
  lastTimeUpdate += secondsPassed * 1000;

  while (secondsPassed--) {
    currentSecond++;
    if (currentSecond >= 60) {
      currentSecond = 0;
      currentMinute++;
      if (currentMinute >= 60) {
        currentMinute = 0;
        currentHour++;
        if (currentHour >= 24) {
          currentHour = 0;
          currentDay++;
          if (currentDay > 31) currentDay = 1;
        }
      }
    }
  }

  char horaBuffer[6];
  char dataBuffer[11];
  sprintf(horaBuffer, "%02d:%02d", currentHour, currentMinute);
  sprintf(dataBuffer, "%02d/%02d/%04d", currentDay, currentMonth, currentYear);

  dados.hora = String(horaBuffer);
  dados.data = String(dataBuffer);
}

bool scheduleAlert(const AlertItem &item, uint8_t hour, uint8_t minute) {
  if (scheduledCount >= MAX_SCHEDULED_ALERTS) return false;

  ScheduledAlert &slot = scheduledAlerts[scheduledCount];
  slot.alert = item;
  slot.hour = hour;
  slot.minute = minute;
  slot.fired = false;
  slot.valid = true;

  scheduledCount++;
  return true;
}

bool parseTimePayload(const String& payload, int& y, int& m, int& d, int& hh, int& mm) {
  String s = payload;
  s.trim();
  s.replace(" ", "|");

  int p = s.indexOf('|');
  if (p < 0) return false;

  String datePart = s.substring(0, p);
  String timePart = s.substring(p + 1);

  datePart.trim(); timePart.trim();
  if (datePart.length() < 10 || timePart.length() < 5) return false;
  d = datePart.substring(0, 2).toInt();
  m = datePart.substring(3, 5).toInt();
  y = datePart.substring(6, 10).toInt();

  hh = timePart.substring(0, 2).toInt();
  mm = timePart.substring(3, 5).toInt();

  if (y < 2020 || m < 1 || m > 12 || d < 1 || d > 31) return false;
  if (hh < 0 || hh > 23 || mm < 0 || mm > 59) return false;
  return true;
}

void handleBLECommand(String cmd) {
  cmd.trim();
  
  if (cmd == "RESET_PASSOS") {
    dados.passos = 0;
  }
  else if (cmd == "SIMULAR_QUEDA") {
    dados.queda = true;
    fallUntil = millis() + 3500;
  }
  else if (cmd == "LIMPAR_QUEDA") {
    dados.queda = false;
  }
  else if (cmd.startsWith("ALERT|")) {

    int p1 = cmd.indexOf('|');
    int p2 = cmd.indexOf('|', p1 + 1);
    int p3 = cmd.indexOf('|', p2 + 1);
    int p4 = cmd.indexOf('|', p3 + 1);
    if (p1 == -1 || p2 == -1 || p3 == -1 || p4 == -1) return;
    String typeStr = cmd.substring(p1 + 1, p2);
    String durationStr = cmd.substring(p2 + 1, p3);
    String timeStr = cmd.substring(p3 + 1, p4);
    String messageStr = cmd.substring(p4 + 1);

    int hour = timeStr.substring(0,2).toInt();
    int minute = timeStr.substring(3,5).toInt();

    AlertItem item;

    if (typeStr == "WATER") item.type = ALERT_WATER;
    else if (typeStr == "MEDICINE") item.type = ALERT_MEDICINE;
    else if (typeStr == "SLEEP") item.type = ALERT_SLEEP;
    else if (typeStr == "APPOINTMENT") item.type = ALERT_APPOINTMENT;
    else item.type = ALERT_CUSTOM;

    item.message = messageStr;
    item.duration = durationStr.toInt();
    scheduleAlert(item, hour, minute);
  }

  if (cmd.startsWith("TIME|")) {
    String payload = cmd.substring(5);
    int y,m,d,hh,mm;
    if (parseTimePayload(payload, y,m,d,hh,mm)) {
      applyTime(y,m,d,hh,mm);
      uiNeedsRefresh = true;
    }
    return;
  }
}

// ==========================
// BLE CALLBACKS
// ==========================
void drawCurrentUI();

class HAWKServerCallbacks : public BLEServerCallbacks {
  void onConnect(BLEServer *server) override {
    bleConnected = true;
    dados.ble = true;
    dados.aparelho = "Celular conectado";
    dados.sync = "Aguardando sync";
    drawCurrentUI();

    BLEDescriptor* desc = pStatusChar->getDescriptorByUUID(BLEUUID((uint16_t)0x2902));
    if (desc != nullptr) {
      uint8_t notifyOn[] = {0x01, 0x00};
      desc->setValue(notifyOn, 2);
    }
    uiNeedsRefresh = true;
  }

  void onDisconnect(BLEServer *server) override {
    bleConnected = false;
    dados.ble = false;
    dados.aparelho = "Aguardando";
    dados.sync = "Nao sincronizado";
    BLEDevice::startAdvertising();
    drawCurrentUI();
  }
};
class SyncCallbacks : public BLECharacteristicCallbacks {
  void onWrite(BLECharacteristic *pCharacteristic) override {
    String incoming = pCharacteristic->getValue().c_str();
    incoming.trim();
    if (incoming.length() == 0) return;

    updateDateFromSyncString(incoming);
    drawCurrentUI();
  }
};
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
void loop() {
  updateRtcFromMillis();
  updateGeneralData();
  
  // Funções dos sensores (Agora rodando na mesma fluidez do Arquivo 2)
  updateMPUData();
  updateMAX30102();
  
  handleButtons();

  if (uiNeedsRefresh) {
    uiNeedsRefresh = false;
    drawCurrentUI();
  }

  if (dados.queda && appState == STATE_WATCH) {
    appState = STATE_ALERT_FALL;
    drawCurrentUI();
  }

  // ==========================
  // GERENCIADOR DE ALERTA REMOTO
  // ==========================
  if (!remoteAlertActive && hasPendingAlert()) {
    if (dequeueAlert(currentAlert)) {
      remoteAlertActive = true;
      remoteAlertUntil = millis() + currentAlert.duration;
      appState = STATE_REMOTE_ALERT;
      drawCurrentUI();
    }
  }
  processScheduledAlerts();
  
  if (remoteAlertActive && millis() > remoteAlertUntil) {
    remoteAlertActive = false;
    appState = STATE_WATCH;
    drawCurrentUI();
  }

  if (bleConnected && millis() - lastBLESend > 200) {
    lastBLESend = millis();
    sendBLEStatus();
  }

  static unsigned long lastMotionUI = 0;
  if (appState == STATE_WATCH && currentScreen == SCREEN_MOTION && millis() - lastMotionUI > 120) {
    lastMotionUI = millis();
    updateMotionDynamic();
  }

  static unsigned long lastHealthUI = 0;
  if (appState == STATE_WATCH &&
      (currentScreen == SCREEN_HOME || currentScreen == SCREEN_HEALTH) &&
      millis() - lastHealthUI > 200) {
    lastHealthUI = millis();
    updateHealthDynamic(); // ✅ sem fillScreen
  }
}

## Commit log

2026-05-29 Revise README for HAWK project details
    Updated README to provide detailed project overview, objectives, features, architecture, and instructions for the HAWK wearable device for elderly care.
2026-05-29 Clean up MAX30102 debug code and comments
    Removed debug prints and comments for clarity.
2026-05-30 Add esquematicos directory with electronic and mechanical files
    Added new directories for electronic and mechanical schematics with relevant files.
2026-05-30 Update image width in README
    Increased image width for HAWK watch prototype.
2026-05-30 Increase image width for HAWK prototype
    Updated image width in README for better visibility.
2026-05-30 Insert components image in README
    Add image for components in README
2026-05-30 Revise README with new project details and badges
    Updated project description and added badges for platform, language, firmware, board, communication, and status.
